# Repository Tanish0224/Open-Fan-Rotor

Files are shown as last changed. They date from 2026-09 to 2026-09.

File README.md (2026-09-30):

# Open-Fan Rotor

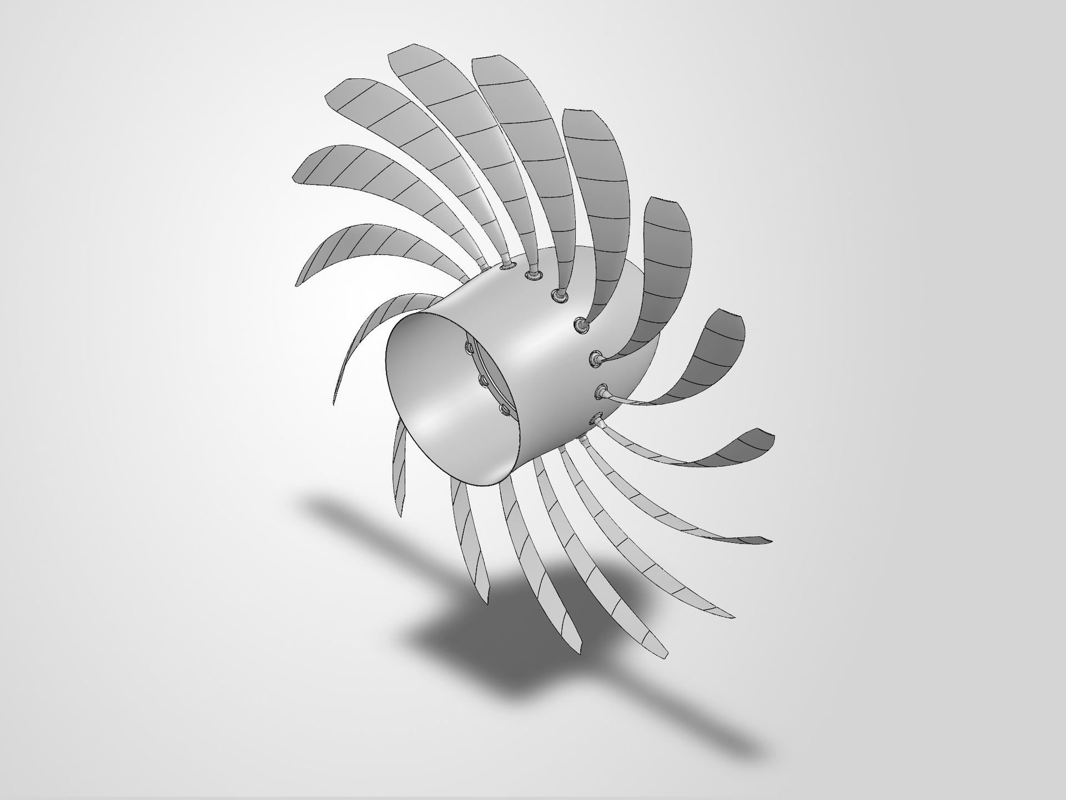
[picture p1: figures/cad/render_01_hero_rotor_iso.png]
16-blade rotor assembly


A 16-blade swept open-fan (unducted) rotor designed for Mach 0.75 cruise at 35,000 ft. The project runs from a
blade-element design through scripted SolidWorks CAD to a 360° CFD campaign in ANSYS Fluent. The first CFD run
exposed a camber error in the built blade. After it was corrected, a series of design changes tested how close
the rotor could get to its 0.75 propulsive-efficiency target. The highest design-RPM efficiency reached was
η_p = 0.572 (case V08).

## Design

| | |
|---|---|
| Design point | Mach 0.75, 10,668 m (35,000 ft) ISA, isolated rotor |
| Diameter / speed | 3.5 m; 1294.5 rpm (rotational tip Mach 0.80, helical tip Mach 1.0966) |
| Design thrust | 14,451.5 N, from a thrust loading τ = 0.08 |
| Method | actuator-disk sizing + Adkins–Liebeck minimum-induced-loss blade design |
| Blades | 16, chosen from a blade-count trade |
| Sweep | circumferential, 44.66° at the tip |

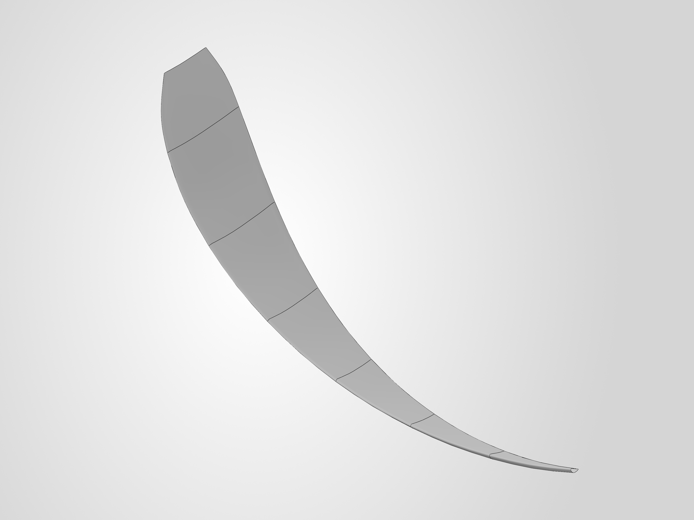
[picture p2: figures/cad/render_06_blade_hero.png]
PRIME blade

*PRIME, the design master blade: circumferential sweep along the span and twist from the root (lower right) to
the tip.*

The blade is generated from the design table by Python scripts driving the SolidWorks API. These are the designs
that matter in the CFD campaign:

| Design | What it is |
|---|---|
| **PRIME** | the v03 design master; its 0.006c trailing edge was too thin to mesh, so the CFD used the variants below |
| **V04cf** | PRIME's design with the camber sign corrected; trailing edge thickened to 0.020c for meshing |
| **V05n16** | NACA 16-series sections in place of NACA 4-digit |
| **V06e** | v06 BEM redesign: design C_l 0.70/0.40 → 0.45/0.26 (root/tip), more chord, root t/c 0.20 → 0.12 |
| **V08** | V06e with the trailing-edge parameter reduced to 0.012c (meshed as 0.0188c) |

BEM design distributions

## Key results

V08 is the reference case and has the highest recorded design-RPM efficiency in this CFD campaign, at
1294.5 rpm and Mach 0.75.

| Thrust | Torque | Shaft power | η_p |
|---:|---:|---:|---:|
| 6548.01 N | 18788.06 N·m | 2.5469 MW | 0.57179 |

- V08 produced about 45 % of the 14,451.5 N design-thrust value; the 0.75 efficiency target was not reached.
- Thrust and torque vary by 1.93 % / 1.12 % over the full second-order history, against a 1 % convergence
  criterion; over the last five checkpoints the variation is 0.80 % / 0.47 %.
- Each case uses a single mesh without prism layers. Mesh independence and experimental validation were not
  assessed.

Results for every case are in [`RESULTS.md`](RESULTS.md).

## What changed

The first run, V03, gave net drag (T = −845.8 N) while absorbing shaft power. Measuring the built blade showed
that the section camber was on the wrong side of the chord for the direction of rotation. Flipping it (V04cf)
gave positive thrust: 4209.9 N at the last checkpoint, although that run never settled. PRIME itself still
carries the error; it is retained unchanged as the record of the built design.

From the corrected blade, the section family was changed first (V05n16), then the BEM loading and chord
distribution (V06e), and finally the trailing-edge parameter (V08). V06e changes several parameters at
once, so these are staged design iterations rather than one-parameter experiments.

Three changes were then tested around V08: a uniform de-pitch (V10), 6° more sweep (V12) and a local root
de-pitch (V15). All three lowered efficiency and missed the predictions written before each run. A hub boundary-condition test (V14)
showed that the negative loading near the root does not come from the hub boundary layer in this model. The
loading plots show the pattern: the outer span gets close to the design loading, while the inner half stays well
below it.

Radial loading

The structural side of the rotor, with root modules, a 16-station carrier and a spinner shell, was built as a
fully mated CAD assembly, and the blade retention was checked with screening FEA in ANSYS MAPDL.

## More detail

| | |
|---|---|
| [`design/`](design/) | design point, BEM method, blade-count trade, the two design families |
| [`cad/`](cad/) | how PRIME was built, the CFD geometries, CAD vs meshed trailing edge, naming |
| [`cfd_method/`](cfd_method/) | solver setup, mesh, boundary conditions, convergence criteria |
| [`cfd_campaign/`](cfd_campaign/) | the campaign case by case, including what did not work |
| [`RESULTS.md`](RESULTS.md) | every recorded CFD result, including diagnostic and off-design cases |
| [`LIMITATIONS.md`](LIMITATIONS.md) | numerical and modelling limitations |
| [`structural/`](structural/) | structural assembly and screening FEA |
| [`reproducibility/`](reproducibility/REPRODUCE.md) | what can be re-run from this repository |
| [`EVIDENCE_INDEX.md`](EVIDENCE_INDEX.md) | where each number and claim comes from |
| [`figures/`](figures/) | all figures and their source data |
| [`reports/`](reports/) | lessons learned |
| [`history/`](history/) | superseded geometry, old drawings and cases without a result |

This repository has not undergone independent external review.

Project and analysis by **Tanish Shetty**. Tools: Python (NumPy, SciPy, Matplotlib), SolidWorks 2026 API,
ANSYS Fluent 2025 R1, ANSYS MAPDL 2025 R1. Code is MIT-licensed. CAD, drawings, figures and data are covered by
[`ASSET_NOTICE.md`](ASSET_NOTICE.md).

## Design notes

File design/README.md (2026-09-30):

# Design (BEM)

An open fan drops the nacelle, which helps propulsive efficiency but leaves the blade tips in supersonic relative
flow even at moderate flight Mach numbers. Without a duct, sweep is the main way to manage that. The rotor was
designed around this constraint. The blade-element (BEM) model here sets the geometry, and the CFD campaign
measures how the built rotor actually performs.

## Design point

| Quantity | Value | Basis |
|---|---|---|
| Flight condition | Mach 0.75, 10,668 m (35,000 ft) ISA | requirement |
| Diameter | 3.5 m | design decision |
| Rotational tip Mach | 0.80 | requirement → 1294.49 rpm, ω = 135.559 rad/s |
| Helical tip Mach | 1.0966 | calculated, √(0.75² + 0.80²) |
| Thrust loading τ = T / (ρ A V0²) | 0.08 | design decision (no aircraft was defined, so there is no aircraft-level thrust requirement) |
| Design thrust | 14,451.5 N | output |

## Method

`openfan_design.py` implements actuator-disk sizing and an Adkins–Liebeck minimum-induced-loss blade-element
design. It uses a Prandtl tip/hub loss factor, closed-form NACA 4-digit sections and a low-order section-drag
estimate. `run_phase1_design.py` runs the design and the blade-count trade.

- **Blade count** is an output. Counts of 14–18 pass the aspect-ratio and chord bounds
  (`results/blade_count_trade.csv`). The smallest count within 0.5 % of the best efficiency among them was chosen:
  **B = 16**.
- **Sweep** follows from a leading-edge-normal Mach limit of 0.78, through cos Λ = 0.78 / M_helical. That gives
  44.66° at the tip. A later check showed that this flat-wing relation over-credits the relief for circumferential
  sweep, so the sections run above their own critical Mach.
- **Internal checks.** Seven closure checks pass, including a 41 → 81 station refinement (`gate_G0` and
  `station_independence` in `results/design_summary.json`). They confirm that the model solves its own equations
  consistently.

## Two design families

| File | Family | Design C_l root / tip, root t/c | Torque | η (model) | Used for |
|---|---|---|---|---|---|
| `results/design_summary.json` | v03 | 0.70 / 0.40, 0.20 | 29,372 N·m | 0.8072 | V03, V04cf, V05n16 |
| `results/design_summary_v06.json` (from `run_v06_design.py`) | v06 | 0.45 / 0.26, 0.12 | 29,818 N·m | 0.7951 | V06e, V08, V10, V12, V14, V15, V16 |
| `results/bem_at_v11_rpm.json` | v06 blade at 1000 rpm, matched thrust | — | 44,073 N·m | 0.6964 | a bound only; not a prediction of V11 |

Both families have the same design thrust (14,451.5 N). Compare each CFD case with its own family; every figure
names the family it uses.

design distributions

## BEM vs CFD

The CFD cases reach only 22–45 % of the design thrust, so BEM and CFD are never compared at matched thrust. The
efficiencies are therefore not directly comparable. The figure below uses BEM as the design reference.

BEM vs CFD

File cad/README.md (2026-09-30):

# CAD and geometry

## How the blade was built

The blade is generated from the BEM design table (`design/results/`) by Python scripts that drive the SolidWorks
API. After each build, a separate script re-opens the part and checks it against the design.

- **v01** failed its own geometry check. The cause was faceted section profiles, which were replaced with smooth
  two-spline sections.
- **v02** passed its check, but a later coordinate check showed the sweep had been built as 0.757 m of axial
  rake, with the tip at 1.879 m instead of 1.75 m. It is kept in `history/superseded_geometry/`.
- **v03 (PRIME)** builds the sweep circumferentially, with 6 mm of rake. It is the design master.

## PRIME

PRIME is `openfan_blade_v03_G1_PRIME_VERIFIED.SLDPRT`, built by `scripts/blade_geometry_v03.py`.

| | |
|---|---|
| SHA-256 | `f5d54c78d1596cdd4fd3df130d34287fe25768e99919c7a82be7b751ab17aeca` |
| Geometry check | 12 of 12 checks passed, before saving and after re-opening (`structural/verification/blade_v03_G1_PRIME_verification.json`) |
| "VERIFIED" in the name | refers to that geometry check: body count, validity, volume, true radius, axial rake, sweep and save/re-open. It says nothing about aerodynamic or structural performance. |
| Known issue | the section camber is on the wrong side of the chord for the direction of rotation. The CFD found it (V03); PRIME uses the same section-placement code. PRIME is retained unchanged as the record of the built design. |

The native SolidWorks file is not included; the hash above identifies it.

| Axial view | Side view |
|---|---|
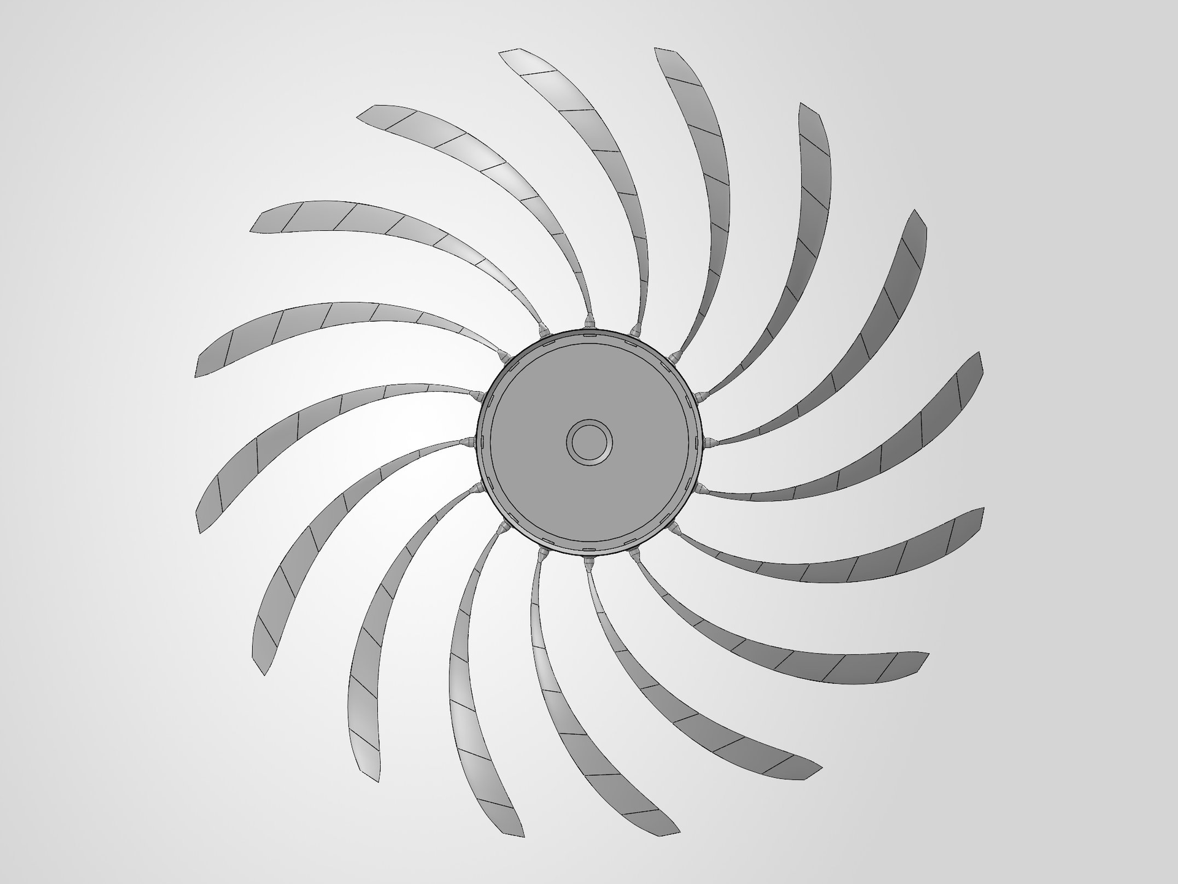
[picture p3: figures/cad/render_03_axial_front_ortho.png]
axial
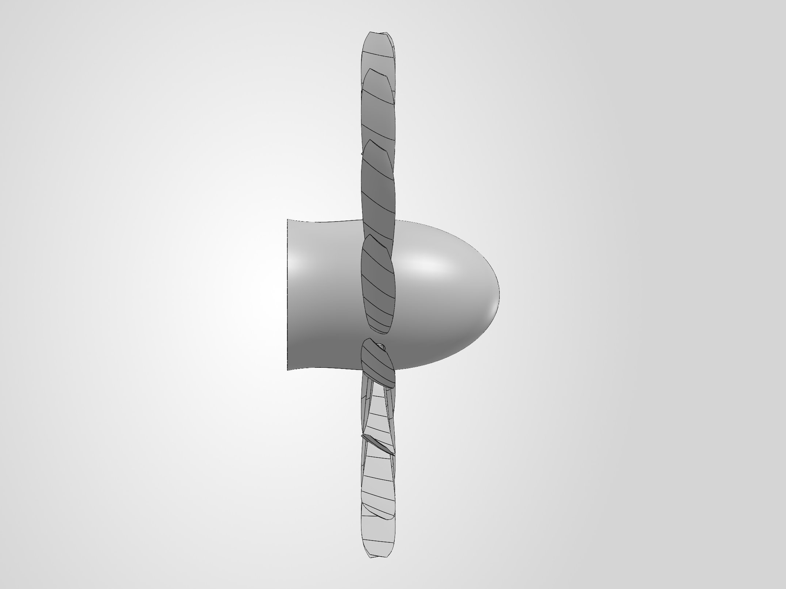
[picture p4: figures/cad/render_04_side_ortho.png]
side
|  |  |

## CFD geometries (`cfd_derivatives/`)

The CFD never used PRIME directly: its 0.006c trailing edge could not be meshed. Each case used its own geometry,
built by the same generator scripts. V03 to V05n16 use PRIME's v03 design table (V05n16 changes the section
family); V06e onward use the v06 design table. The STEP files are the exported geometries.

| File | Case(s) | Change from its parent |
|---|---|---|
| `openfan_blade_v03_CFD_SINGLELOFT.step` | V03 | PRIME with the trailing edge thickened to 0.020c (camber error still present) |
| `openfan_blade_v04_CFD_CAMBERFIX_SINGLELOFT.step` | V04cf | camber sign corrected |
| `openfan_blade_v05_CFD_NACA16_SINGLELOFT.step` | V05n16 | NACA 16-series sections |
| `openfan_blade_v06_CFD_SINGLELOFT.step` | V06, V06c, V06e | v06 BEM design (lower C_l, thinner root) |
| `openfan_blade_v08_CFD_SINGLELOFT.step` | V08, V14 | trailing-edge parameter 0.012c |
| `openfan_blade_v09_CFD_SINGLELOFT.step` | V09, V13 | trailing-edge parameter 0.006c (PRIME's value); could not be meshed |
| `openfan_blade_v10_CFD_SINGLELOFT.step` | V10 | uniform de-pitch −1.77° |
| `openfan_blade_v11_CFD_SINGLELOFT.step` | V11 (1000 rpm, off-design) | re-twisted for 1000 rpm |
| `openfan_blade_v12_CFD_SINGLELOFT.step` | V12 | sweep +6° |
| `openfan_blade_v15_CFD_SINGLELOFT.step` | V15 | root de-pitch −2.40° → 0 at r/R 0.55 |
| `openfan_blade_v16_CFD_SINGLELOFT.step` | V16 (not solved) | root re-pitch +2.40° → 0 at r/R 0.55 |

## Trailing edge: CAD value vs meshed value

The mesher did not resolve the trailing-edge thickness set in CAD. The meshed thickness was measured from the
blade-surface mesh (outboard mean, r/R ≥ 0.70). The measurements are in `cfd_campaign/<case>/te_thickness_*.json`.

| CAD parameter | Cases | Meshed thickness | Mesh | Solution |
|---|---|---|---|---|
| 0.020c | V03, V04cf, V05n16, V06e | 0.0200c (measured for V06e only) | generated | results |
| 0.016c | V08b | — | import failed | none |
| 0.012c | V08, V10, V11, V12, V14, V15, V16 | V08 0.0188c · V11 0.0182c · V12 0.0212c · V15 0.0161c · not measured for V10 (its own mesh, 6,603,468 cells against V08's 6,575,649), V14 (the V08 mesh itself) and V16 (meshed, not solved) | generated | results (V16 not solved) |
| 0.008c | V09b | not measured | generated | solve diverged |
| 0.006c (PRIME) | V09, V13 | — | failed at 7.24 mm and at 2.5 mm size floors | none |

When a result is labelled with a CAD trailing-edge value, read it together with the meshed value.

## Naming

"v03" means three different things in this repository:
- the **v03 blade** (PRIME);
- the **v03 BEM design family**, used by V03 to V05n16 (V06e onward use the v06 family);
- **V03**, the first CFD case.

In prose, CFD cases are written V03 to V16. File and folder names use lower-case tags (`v08`). So a lower-case
tag inside `cfd_campaign/`, or in a `performance_result_*` or `*_orthoquality` file name, is a CFD case.
Elsewhere, "v02", "v03" or "v06" on its own means a CAD or design-table version, as in
`openfan_blade_v03_G1_PRIME_VERIFIED` or `design_summary_v06.json`.

## Scripts (`scripts/`)

`blade_geometry.py` and `blade_geometry_v03.py` generate the section coordinates that the CAD build uses. The
SolidWorks build and check scripts for the structural assembly are in `structural/scripts/`. They need
SolidWorks 2026 to run.

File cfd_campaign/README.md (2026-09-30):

# CFD campaign

The campaign covers 18 labelled case variants (V03–V16) plus one unlabelled +7 % RPM trial. Ten produced a
result: six design-RPM cases, three diagnostics (V03, V04cf, V14) and one off-design case (V11). The other eight
labelled variants and the RPM trial did not produce a result; they are listed in
[`../RESULTS.md`](../RESULTS.md) §4 and [`../history/no_result_cases/`](../history/no_result_cases/). Setup:
[`../cfd_method/`](../cfd_method/). Numbers: [`../RESULTS.md`](../RESULTS.md).

| Folder | Case | Operating point | Role |
|---|---|---|---|
| [`v03_diagnostic_drag_state/`](v03_diagnostic_drag_state/CASE.md) | V03 | design RPM | diagnostic (net drag) |
| [`v04cf_camber_corrected/`](v04cf_camber_corrected/CASE.md) | V04cf | design RPM | diagnostic (unsettled) |
| [`v05n16_naca16_sections/`](v05n16_naca16_sections/CASE.md) | V05n16 | design RPM | design iteration |
| [`v06e_cl_chord_schedule/`](v06e_cl_chord_schedule/CASE.md) | V06e | design RPM | design iteration |
| [`v08_reference_case/`](v08_reference_case/CASE.md) | V08 | design RPM | reference case |
| [`v10_uniform_depitch/`](v10_uniform_depitch/CASE.md) | V10 | design RPM | experiment on V08 |
| [`v11_1000rpm_offdesign/`](v11_1000rpm_offdesign/CASE.md) | V11 | **1000 rpm, off-design** | separate investigation |
| [`v12_sweep_plus6deg/`](v12_sweep_plus6deg/CASE.md) | V12 | design RPM | experiment on V08 |
| [`v14_hub_bc_diagnostic/`](v14_hub_bc_diagnostic/CASE.md) | V14 | design RPM | boundary-condition diagnostic |
| [`v15_root_depitch/`](v15_root_depitch/CASE.md) | V15 | design RPM | experiment on V08 |

Each folder has a `CASE.md` with the change, the prediction written before the run, the outcome and notes.

## How the campaign went

**Camber error (V03 → V04cf).** The first solution, V03, produced net drag (T = −845.8 N) at design RPM while
still absorbing shaft power. The flow showed almost no axial induction, and the incidence was several degrees
above design. Measuring the built blade surfaces showed that the section camber had been placed on the wrong
side of the chord for the direction of rotation. Correcting that one sign (V04cf) gave positive thrust: 4209.9 N
at the last checkpoint. V04cf diverged at iteration 246, so the value is not settled. PRIME uses the same
section-placement code and carries the same error.

camber correction

**Design iterations (V05n16 → V06e → V08).** From the corrected blade, three things were changed in turn:

- the section family to NACA 16-series, with thickness and mean line together (V05n16);
- the BEM loading and chord distribution: lower design C_l at root and tip, more chord and a thinner root, all
  changed together (V06e);
- the trailing-edge parameter, from 0.020c to 0.012c (V08).

V06e changes several parameters at once, so these are staged design iterations rather than one-parameter
experiments. V08 gave the highest design-RPM efficiency, η_p = 0.572. Its CAD trailing edge is 0.012c, but the
mesh resolved 0.0188c, so V08 really tests a thinner aft section rather than a 0.012c edge. The V08
prediction was only partly met. Efficiency came out 0.0018 above the predicted band (0.545–0.570), but the
prediction also expected shaft torque to fall, since the change was meant to cut base drag, and torque rose
4.45 % relative to V06e.

**Experiments around V08 (V10, V12, V15).** Each of these changes one design feature of V08. Each run missed
the efficiency prediction written beforehand. The meshes also differ from V08's (V10 +0.4 %, V12 +9.1 %,
V15 −0.4 % in cell count), and the meshed trailing edges of V12 and V15 differ as well. So none of the three is
a perfectly clean one-variable comparison.

| Case | Change | η_p | What it showed | What it did not show |
|---|---|---:|---|---|
| V10 | uniform de-pitch −1.77° | 0.43856 | thrust fell 51 % | the proposed shock mechanism: sectional data were not exported |
| V12 | sweep +6° | 0.53417 | efficiency below both predicted bands | a clean sweep effect (mesh +9.1 %, different meshed trailing edge) |
| V15 | root de-pitch −2.40° → 0 at r/R 0.55 | 0.55670 | root loading got worse, and the change also affected loading outboard | what incidence correction the root actually needs |

experiments
*Change in thrust, torque and efficiency relative to V08, against V08's own full-history thrust spread.*

**Hub boundary layer (V14).** V14 re-runs the V08 case with zero-shear hub walls, with the same geometry and
mesh. The negative root loading got deeper (dT/dr at r/R 0.40 from −1369 to −1858 N/m), so the hub boundary
layer is not what causes it in this model. V14 is a diagnostic, not a design.

**Off-design (V11).** A blade re-twisted for 1000 rpm reached η_p = 0.656. It is the only case that passes both
convergence windows. Speed and twist changed together, so it cannot be compared directly with the design-RPM
cases.

## What did not work

- **More sweep (V12)** and **root de-pitch (V15)** both lowered efficiency. The opposite-sign root change (V16)
  was built and meshed, but it was not solved.
- **Uniform de-pitch (V10)** cut thrust by half. The mechanism behind the prediction was never tested.
- **PRIME's 0.006c trailing edge** could not be volume-meshed at either size floor tried (V09 at 7.24 mm, V13 at
  2.5 mm). A 0.008c version meshed, but its solve diverged (V09b).
- **The design sweep law** over-credits the Mach relief for circumferential sweep. The analysed sections run
  above their own critical Mach at the design condition.

## Files in the case folders

- **Recorded** files are copied byte-for-byte from the project records. That includes the result files,
  loading, polars, trailing-edge and mesh-quality records.
- **Derived** files were produced for this repository from recorded data:
  - `residuals_*.csv`, from the solver logs;
  - `blade_yplus_node_statistics_*.json`, from the blade-surface exports;
  - `campaign_summary.json`, from `reproducibility/verify_results.py`.

  The scripts that produced the residual and y⁺ files are not included.

A few recorded fields need care:

- The stored `rpm` field is stale in some files. V11's reads 1294.49, while ω gives 1000 rpm.
- `settled_within_1pct` refers to the rolling window only.
- The polars for V04cf, V05n16 and V06e were computed on a zero-induction basis that was later found to be
  wrong. They were not regenerated.

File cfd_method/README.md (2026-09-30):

# CFD method

This setup applies to every case in `cfd_campaign/` unless a case page says otherwise. The Fluent settings are in
the journal templates in `journals/`, which are the V08 setup and solve journals with absolute file paths removed.
The journals for V05n16, V06e, V09b, V10, V12 and V15 are identical to V08's apart from the case tag and the
solver-assigned zone ID. V11 differs only in ω. V14 re-reads the V08 case and changes only the hub-wall condition
(`setup_v14_hub_bc_template.jou`).

## Setup

| Item | Setting |
|---|---|
| Solver | ANSYS Fluent 2025 R1, 3-D, steady (pressure-velocity coupling scheme not set in the journals; solver default) |
| Domain | 360° annulus containing all 16 blades; far field to r = 7 m, z = −7 … +10.5 m |
| Frame | multiple reference frame: rotating cylindrical zone r ≤ 2.0 m, z = −1 … +1 m; outer zone stationary |
| Rotation | ω = −135.559045147 rad/s about +z in the case journals (V04cf onward), i.e. 1294.49 rpm about −z; V11: −104.719755 rad/s (1000 rpm) |
| Turbulence | k-ω SST |
| Fluid | air, ideal gas, three-coefficient Sutherland viscosity, energy equation on |
| Inlet / far field | pressure far-field, p = 23,842.27 Pa, T = 218.808 K, Mach 0.75 along +z |
| Outlet | pressure outlet, 23,842.27 Pa |
| Walls | blade and hub no-slip (V14: hub zero-shear) |
| Discretisation | 60 first-order iterations, then second order |
| Schedule | 60 first-order + 9 × 60 second-order iterations requested; force and moment reported at every 60-iteration checkpoint (S1–S10). Fluent's default residual stop ended some runs a few iterations early. |
| Mesh | Fluent Meshing watertight workflow, tetrahedral, size 7.24 mm – 0.5 m, growth 1.2, curvature and proximity sizing; **no prism layers**; about 6–7 M cells |

## Mesh quality

The first 4.0 M-cell mesh diverged in three solves. The cause was degenerate surface triangles carried over from
the CAD tessellation (minimum orthogonal quality of zero), so that mesh was rejected. From then on every
mesh was checked before it was solved. The per-case quality records are in
`cfd_campaign/<case>/openfan_*_vol_orthoquality.json`.

## Forces and efficiency

- Thrust T = −F_z and torque Q = M_z come from Fluent's force and moment reports on the blade walls. Hub walls
  are excluded.
- Shaft power is P = Q·|ω|, and propulsive efficiency is η_p = T·V0/P with V0 = 222.40 m/s.
- η_p is only reported when T > 0 and P > 0. In a windmill or drag state the ratio of two negative numbers can
  look like a plausible efficiency.
- Two separately written parsers (`postprocessing/compute_performance.py` and
  `postprocessing/independent_extract.py`) give identical values for the cases where both were run.

## Convergence

Convergence is judged on thrust and torque over two windows:

| Window | Definition |
|---|---|
| Rolling | peak-to-peak / mean of T and Q over the last 5 checkpoints; 1 % limit |
| Full history | peak-to-peak / mean of T and Q over S2–S10 (all second-order checkpoints); 1 % limit |

Before any CFD was run, a stricter target (G2) was set:
- at least three refined meshes, with < 2 % change between the two finest;
- residuals down at least 4 orders;
- T and Q stationary over the final 500+ iterations;
- y⁺ within the range the wall treatment needs.

No design-RPM case met it. There is one mesh per case, residuals drop about 3 orders, the full-history spread is above
1 % in every case, and y⁺ is too high without prism layers. The original plan was to report no
performance numbers unless G2 was met; instead, the results are reported with their convergence numbers beside
each one ([`../RESULTS.md`](../RESULTS.md)).

convergence

## Post-processing scripts (`postprocessing/`)

| Script | Purpose | Input (not published) |
|---|---|---|
| `compute_performance.py` (+ `bem_reference.py`, `case_omega.py`) | T, Q, P, η from the Fluent transcript; per-family BEM reference; per-case ω | Fluent transcript file (`.trn`) |
| `independent_extract.py` | a second, separately written parser of the force reports | Fluent transcript file (`.trn`) |
| `convergence_character.py` | window statistics and trend test | Fluent transcript file (`.trn`) |
| `measure_te_thickness.py` | meshed trailing-edge thickness from the blade-surface export | blade-surface CSV |

These scripts show how the recorded files were produced. Their inputs, the Fluent transcripts and field exports,
are too large to include (see [`../reproducibility/REPRODUCE.md`](../reproducibility/REPRODUCE.md)). From the
recorded JSON files, `reproducibility/verify_results.py` recomputes shaft power, efficiency, rpm and both
convergence windows. Thrust, torque, mesh counts and the other values are the recorded inputs.

The scripts that produced the sectional polars, blade-loading integrals, velocity triangles, y⁺ statistics,
residual histories and span accounting are not included. Code comments refer to some of them (for example
`sectional_polar_from_cfd.py` and `analyse_blade_loading.py`). Their outputs are in `cfd_campaign/`, unchanged,
but cannot be regenerated from this repository.

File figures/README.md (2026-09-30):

# Figures

Every plot is regenerated by `src/make_figures.py` from data files in this repository. No number on a figure is
typed by hand; each annotation is computed from the plotted case's own data.

The three blade-to-blade field images also need the field exports (`b2b_r75_<case>.csv`). Those are not included
because of their size; they are identified by hash in `reproducibility/unpublished_evidence_register.json`.

Every CFD figure names its case and operating point.

## CFD (`cfd/`)

| File | Case(s) and operating point | Source data | Caption |
|---|---|---|---|
| `cfd_convergence_design_rpm.svg` | V05n16, V06e, V08, V10, V12, V14, V15 — design RPM | `performance_result_*.json` checkpoints | Thrust and torque at each checkpoint, normalised to the last checkpoint. Both convergence windows are shaded with their pass/fail result. |
| `cfd_v11_1000rpm_offdesign_convergence.svg` | V11 — **1000 rpm, OFF-DESIGN** | V11 checkpoints | As above, for the separate off-design investigation. |
| `cfd_v08_residuals.svg` | V08 — design RPM | `residuals_v08.csv` (derived from the solver log) | Scaled residuals: continuity drops 3.0 orders against the 4 required. |
| `cfd_radial_loading_design_rpm.svg` | V06e, V08, V12, V14, V15 — design RPM | `blade_loading_*.json`; BEM from `design_summary_v06.json` | Sectional thrust and torque loading at nine stations against the v06-family BEM design intent. The outer span approaches design loading; the inner half stays well below it, with negative loading near r/R 0.40. |
| `cfd_radial_loading_lineage_v04cf_v05n16.svg` | V04cf, V05n16 — design RPM | `blade_loading_*.json`; BEM from `design_summary.json` | The same, for the earlier cases, against the v03-family BEM. V04cf is unsettled. |
| `cfd_v11_1000rpm_offdesign_radial_loading.svg` | V11 — **1000 rpm, OFF-DESIGN** | `blade_loading_v11.json` | Sectional thrust loading. No BEM curve: the BEM design exists only for design RPM. |
| `cfd_v08_chordwise_cp.svg` | V08 — design RPM | `blade_loading_v08.json` | Chordwise pressure coefficient at four stations. CAD trailing edge 0.012c; meshed 0.0188c. |
| `cfd_v08_summary.svg` | V08 — design RPM | `performance_result_v08_omega135p559.json`, orthoquality, TE, BEM files | V08's headline values, both convergence windows, the mesh and the trailing edge on one card. |
| `cfd_controlled_experiments_vs_v08.svg` | V10, V12, V15, V14 relative to V08 — design RPM | the case result files | Change in thrust, torque and efficiency relative to V08, against V08's full-history thrust spread. V14 is a hub boundary-condition test; V11 is excluded. The meshes of V10, V12 and V15 differ from V08's by +0.4 %, +9.1 % and −0.4 % in cell count, and the meshed trailing edges of V12 and V15 also differ. |
| `bem_reference_vs_cfd_design_rpm.svg` | design-RPM cases | case results; BEM of the matching family | BEM design intent against recorded CFD thrust and torque. Not at matched thrust; BEM is a reference, not a prediction. |
| `cfd_camber_correction_v03_v04cf.svg` | V03, V04cf — design RPM | the two result files | Net drag becomes positive thrust after the camber sign is corrected. V04cf did not settle. |
| `cfd_mach_b2b_r075_design_rpm.png` | V08, V12, V14, V15 — design RPM | field exports (not included) | Absolute-frame Mach on the blade-to-blade surface at r/R 0.75, on one common colour scale. |
| `cfd_v11_1000rpm_offdesign_mach_b2b_r075.png` | V11 — **1000 rpm, OFF-DESIGN** | field export (not included) | The same quantity and colour scale for the off-design case. |
| `cfd_v08_total_pressure_b2b_r075.png` | V08 — design RPM | field export (not included) | Absolute-frame total pressure at r/R 0.75. |

## Design (`design/`)

| File | Source | Caption |
|---|---|---|
| `bem_spanwise_design_v03_v06_families.svg` | `design_summary.json`, `design_summary_v06.json` | Chord, blade angle, design C_l and thickness ratio for the two BEM design families. This is design intent, not CFD. |

## CAD renders (`cad/`)

`render_01`–`render_05` are captures of the actual CAD assembly: PRIME blades, root modules, carrier and shell.
They were cropped to centre the subject.

| File | View |
|---|---|
| `render_01_hero_rotor_iso.png` | 16-blade rotor, front three-quarter view |
| `render_02_rotor_rear_iso.png` | rear three-quarter view |
| `render_03_axial_front_ortho.png` | axial orthographic view (22.5° blade pitch) |
| `render_04_side_ortho.png` | side orthographic view (blade row in a thin radial disc; 6.1 mm axial rake) |
| `render_05_structure_shell_hidden.png` | structure with the spinner shell hidden: root modules and carrier |
| `render_06_blade_hero.png` | PRIME as a single blade: sweep along the span and twist from root to tip |
| `render_07_blade_root_detail.png` | root region, spinner shell hidden: blade roots, root-module collars and carrier rim |

`render_06` and `render_07` were captured directly from the CAD model (PRIME and the assembly) at 3200 × 2400
and 4000 × 3000. Only the camera and, for `render_07`, the shell's display visibility were changed; the geometry
is exactly as saved. `render_06` is cropped to centre the blade.

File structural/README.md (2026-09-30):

# Structural work

There are two parts: a complete CAD assembly of the rotor, and a set of screening-level FEA runs on the blade
root and retention.

## CAD assembly

The PRIME blade was carried into a 16-blade structural assembly:

- 16 root modules (shank, integral flange, bearing seat);
- a 16-station central carrier;
- a spinner shell with 16 cutouts, which is an aerodynamic fairing, not a load path.

The parts are natively mated in SolidWorks rather than placed by transforms. A re-open check records
(`verification/rotor_assembly_v02_final_verification.json`):

| Check | Value |
|---|---|
| components / mates | 34 / 99, all components fully constrained |
| blade pitch | 22.5° at every station |
| blade-to-root interface gap | 0.000000 m |
| minimum blade-to-blade surface distance | 0.2055 m (true surface distance) |
| root-to-tip axial rake | 0.00612 m |
| shell-to-carrier / shell-to-root clearance | 12.11 mm / 9.88 mm at all 16 stations |

Each component has its own check file in `verification/`. The PRIME blade check (12 of 12 geometry checks,
before saving and after re-opening) is in `verification/blade_v03_G1_PRIME_verification.json`.

The sizing of the shank, seat, carrier web and shell was preliminary closed-form work, so the assembly fixes the
geometry but says nothing about structural margins, fatigue, flutter or manufacturability. The native CAD files
are not included. The drawings made from them are in `history/drawings_2026-08/`.

| Rear view | Structure with the shell hidden |
|---|---|
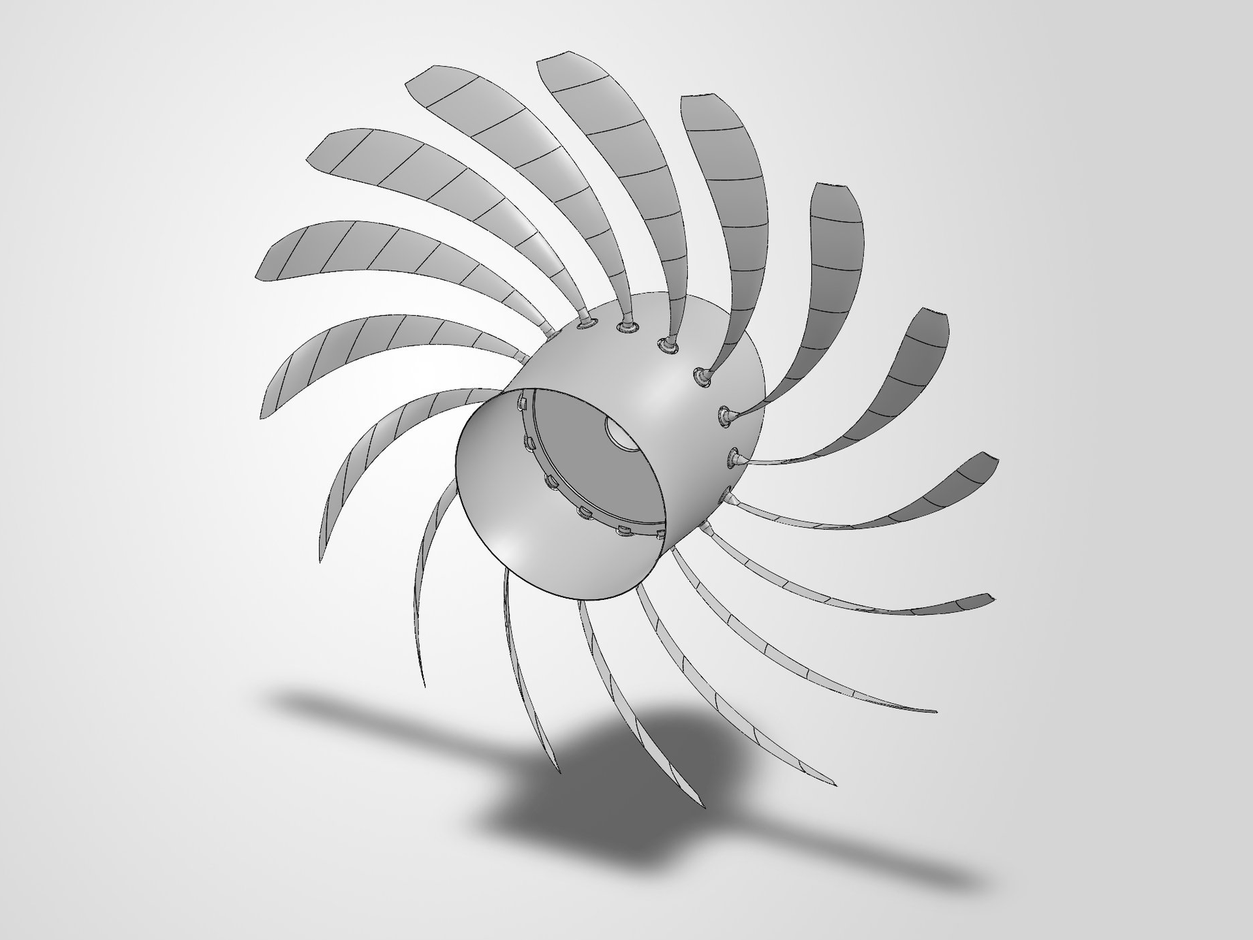
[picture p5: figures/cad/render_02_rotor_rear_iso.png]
rear
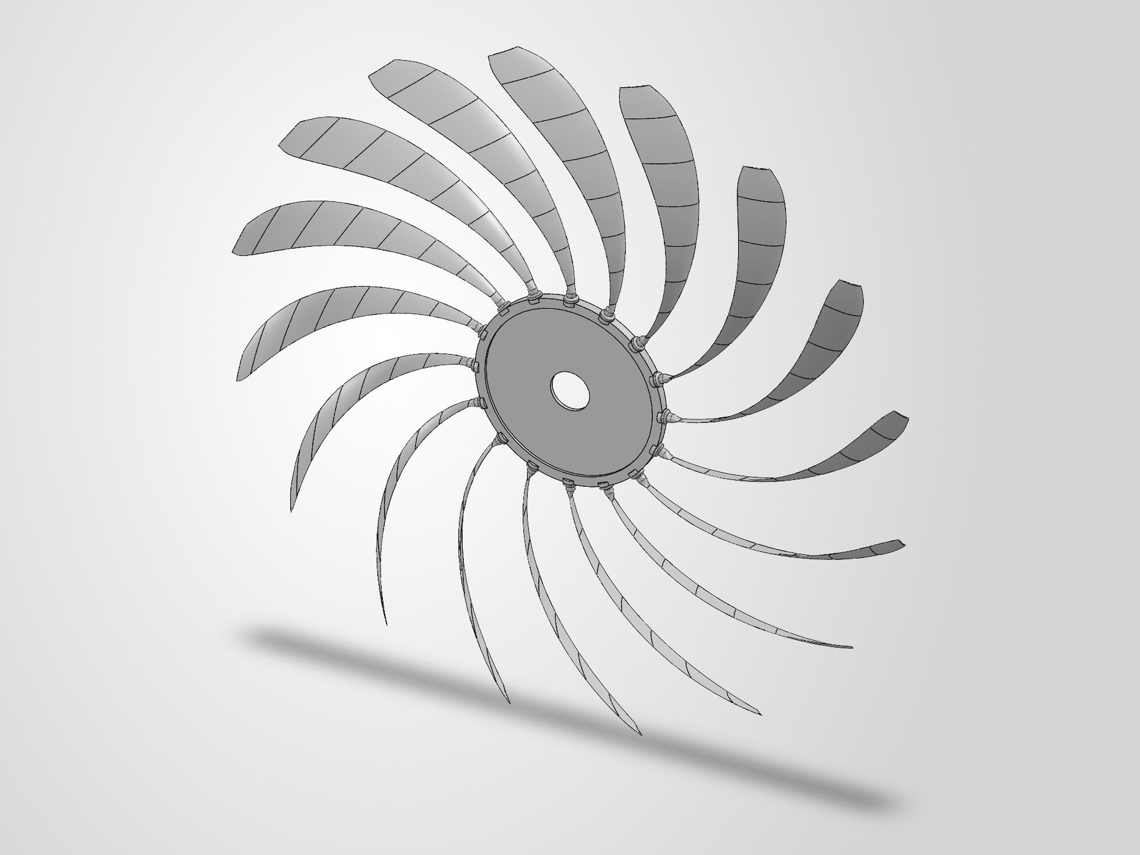
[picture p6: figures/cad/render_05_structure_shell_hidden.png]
structure
|  |  |

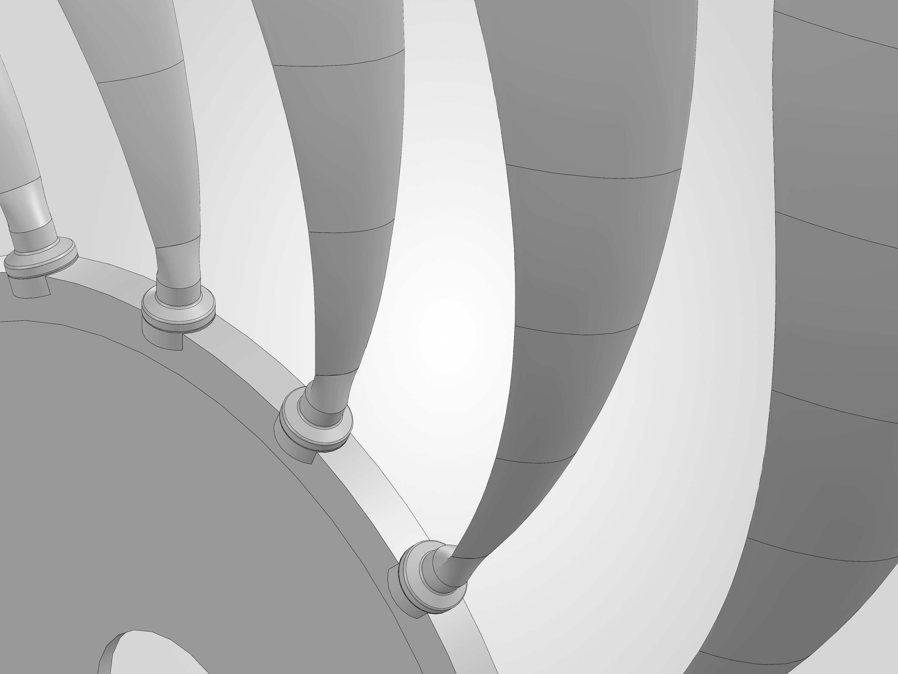
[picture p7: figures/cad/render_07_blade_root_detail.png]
Blade root region

*Root region with the spinner shell hidden: PRIME blade roots in the root-module collars on the carrier rim. This
is the original pad-and-spigot root of the CAD assembly. The later retention study replaced it with a
dovetail-type concept, which the screening FEA found not viable as drawn (Stage 15 below).*

## Screening FEA (ANSYS MAPDL 2025 R1)

After the CAD assembly, a sequence of screening analyses covered the blade root and retention. The stage
reports are identified by hash in `reproducibility/unpublished_evidence_register.json`.

| Stage | What it was | Solved? | Key result | Stage conclusion |
|---|---|---|---|---|
| 1 — root seat | local model of the root seat (solid of revolution) | yes, 10 runs | fillet peak ≈ 770 MPa, K_t 2.74 | screening only; it was not established that the design fails |
| 2 — 22.5° sector | carrier sector plus root module, sector boundary conditions | yes, converged series | fillet peak 815.27 MPa (last refinement step −0.43 %, within a 1 % criterion set beforehand) | peak exceeds a **provisional** 300 MPa allowable (ratio 0.368) |
| 3–14 | load definition, allowables, retention architecture options, CAD | no | decision records | — |
| 15 — Model A | the selected dovetail-type ("C7") retention, 22.5° sector with contact | yes, 14 converged load steps | flank fillet 2526–2537 MPa | **"the C7 geometry at the screening dimensions is not viable as drawn"** |
| 16–17 | failure diagnosis; revised retention CAD | no | — | redesign definition |
| 18 — Model A-R | revised retention, 20 load cases | yes | bending 347 → 665 MPa | governing stress **not mesh-converged**; a full-rotor model is required |
| 19 — mesh closure | refinement study | yes | intermediate fillet converged (−1.51 %); blade peak not converged (+8.46 %, contact-edge singularity) | partial mesh closure |
| 20 — Model C | full 360° rotor, 1,082,992 nodes | yes | axial force balance closes | **global moment balance does not close**; retention not closed |
| 21–23, 25, 27–28 | checks of the moment-balance problem and formulation options | no | missing moment localised to the bolt constraint pairs | open |
| 24, 26 | benchmarks on test blocks (7 solves on a 576-element block; coupling comparison) | yes | constraint and coupling behaviour | benchmarks only, not design results |

**Inputs.** The centrifugal load (163.3 kN in Stages 1–2, 168.71 kN from Stage 15) came from an earlier sizing
step. Bending moments were derived from the design loading. Material allowables were provisional. The stage 1
report does not name the aerodynamic dataset behind its moments.

**What it shows.** The retention region, as first drawn, is highly stressed. The first retention concept fails
its screening, and the full-rotor model has an unresolved moment-balance problem. The work does not give a factor
of safety against a sourced allowable, a fatigue life, or a working retention design.

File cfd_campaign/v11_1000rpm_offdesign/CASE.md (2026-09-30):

# V11 — 1000 rpm off-design case

| | |
|---|---|
| Classification | off-design case (1000 rpm) |
| Operating point | 1000.0 rpm (ω = -104.72 rad/s), flight Mach 0.75, 10,668 m ISA |
| Change | Rotational speed 1294.5 → 1000 rpm AND the blade re-twisted for the new speed (+4.07° root to +7.35° tip). Two coupled changes; their effects cannot be separated. |
| Mesh | 6,545,217 (min orthogonal quality 0.00070; 375 cells below 0.01); no prism layers |
| Thrust T | 5848.05 N |
| Torque Q | 18939.19 N·m |
| Shaft power P = Q·\|ω\| | 1.9833 MW |
| Propulsive efficiency η = T·V0/P | 0.65578 |
| Rolling window (last 5 checkpoints), T / Q | 0.12 % / 0.07 % — within the 1 % bound |
| Full second-order history (S2–S10), T / Q | 0.76 % / 0.37 % — within the 1 % bound |
| Residuals (continuity) | 1 → 0.000998 = 3.00 orders over 547 iterations (≥ 4 orders required by the G2 criterion) |
| Trailing edge | CAD parameter 0.012c; meshed (outboard mean, r/R ≥ 0.70) 0.0182c |
| Blade y+ (node-based) | median 420.7, 95th percentile 533.5, max 1673.0; 92 % of nodes above 300 |
| Validation | none (no experimental or benchmark data) |

## Prediction

η band 0.58–0.67 (central 0.62), written before the run; main check: effective lift-curve slope should rise.

## Outcome

η fell inside its band, and both convergence windows pass. At 1000 rpm, with a re-twisted blade, the case is not comparable with V08.

## Notes

- The stored `rpm` field in the result file reads 1294.49 (stale); ω = −104.72 rad/s ⇒ 1000.0 rpm.
- The solver log shows Fluent's own residual stop at iteration 547 ('solution is converged' on its default residual criterion). An earlier project report stated that V11 ran the full 600-iteration schedule; the log is the primary record. Fluent's default stop is not the convergence criterion used in this repository.
- Mesh tail quality is worse than V08 (minimum orthogonal quality about 4× lower).

## Files in this folder

Recorded files are published unchanged; derived files are marked.

- `blade_loading_v11.json` (recorded)
- `blade_yplus_node_statistics_v11_1000rpm_offdesign.json` (derived)
- `convergence_character_v11.json` (recorded)
- `openfan_v11_vol_orthoquality.json` (recorded)
- `performance_result_v11_omega104p720.json` (recorded)
- `residuals_v11_1000rpm_offdesign.csv` (derived)
- `sectional_polar_v11.json` (recorded)
- `te_thickness_v11.json` (recorded)
- `velocity_triangle_BUILT_v11.json` (recorded)

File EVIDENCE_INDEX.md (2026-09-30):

# Evidence index

Where each number and claim in this repository comes from.

**Evidence classes.**

| Class | Meaning |
|---|---|
| **PRIMARY** | a recorded file produced by the design code, CAD check, solver or its extraction, published unchanged |
| **DERIVED** | computed for this repository from primary data (the source is stated). The comparison scripts are published; the scripts that extracted the residual histories, y⁺ statistics and sectional and loading files are not (see `reproducibility/REPRODUCE.md`) |
| **DESIGN INTENT** | a BEM/analytical design value, not a measurement |
| **DIAGNOSTIC** | a real result that answers a diagnostic question, not a performance question |
| **HISTORICAL** | superseded, kept for the record |

"Register" means `reproducibility/unpublished_evidence_register.json`: a file that exists, identified by name and
SHA-256, but is not published.

## Design

| Claim | Class | Evidence | Method |
|---|---|---|---|
| Design point: Mach 0.75, 10,668 m, D 3.5 m, tip Mach 0.80, τ 0.08 | DESIGN INTENT | `design/results/design_summary.json` (`inputs`, `operating_point`) | defined requirements |
| Helical tip Mach 1.0966; 1294.49 rpm | DESIGN INTENT | `design_summary.json` → `operating_point` | calculation (re-runs identically) |
| 16 blades chosen from a trade study | DESIGN INTENT | `design/results/blade_count_trade.csv`; `run_phase1_design.py` | aspect-ratio and chord bounds + 0.5 % efficiency tie-break |
| Tip sweep 44.66° | DESIGN INTENT | `design/results/design_table.csv` | cos Λ = 0.78 / M_helical |
| The sweep law over-credits Mach relief; sections run above their critical Mach | DERIVED | register: `sweep_relief_audit.json`, `critical_mach_audit.json` | geometric projection check; 2-D panel method |
| BEM η 0.8072 (v03 family), 0.7951 (v06 family); design thrust 14,451.5 N | DESIGN INTENT | `design_summary.json`, `design_summary_v06.json` | Adkins–Liebeck design; 7 internal closure checks (`gate_G0`, `station_independence`) |

## Geometry

| Claim | Class | Evidence | Method |
|---|---|---|---|
| PRIME passes a 12-check geometry check (before saving and after re-opening) | PRIMARY | `structural/verification/blade_v03_G1_PRIME_verification.json` | independent re-open and measurement |
| PRIME identity | PRIMARY | SHA-256 in `cad/README.md`; register (native file) | hash |
| v02 was built with 0.757 m axial rake and a 1.879 m tip | PRIMARY | same file (`v02_Z_span_m`, `v02_true_radius_max_m`) | coordinate readback |
| Camber on the wrong side of the chord in V03 (and in PRIME's section code) | PRIMARY | register: `camber_orientation_check.json`, `camber_stl_check.json`, `STAGE35_CAMBER_INVERSION_ROOT_CAUSE.md` | mean-line direction measured on the solved blade, the CAD source and the exported CAD surfaces |
| CFD derivative geometry per case | PRIMARY | `cad/cfd_derivatives/*.step` | exported CAD |
| Meshed trailing edge differs from the CAD value (0.0161c–0.0212c for 0.012c CAD) | PRIMARY | `cfd_campaign/*/te_thickness_*.json` | measured from the blade-surface mesh |
| 0.006c trailing edge could not be meshed; 0.008c diverged | PRIMARY | register: `v09_TE006_MESH_FAILURE.json`, `v13_TET_INIT_FAILED_definitive_root_cause.json`, `v09b_TE008_DIVERGED.json` | mesher and solver records |

## CFD

| Claim | Class | Evidence | Method |
|---|---|---|---|
| V08 T = 6548.01 N, Q = 18788.06 N·m, P = 2.5469 MW, η_p = 0.57179 | PRIMARY → DERIVED check | `cfd_campaign/v08_reference_case/performance_result_v08_omega135p559.json` → `reproducibility/verify_results.py` → `figures/cfd/cfd_v08_summary.svg` | force report; P = Q·\|ω\|, η = T·V0/P recomputed exactly |
| Values for every other case in `RESULTS.md` | PRIMARY → DERIVED check | `cfd_campaign/<case>/performance_result_*.json` → `campaign_summary.json` | as above |
| V08 passes the rolling window and fails the full-history window | DERIVED | `verify_results.py` from the stored checkpoints (matches `convergence_character_v08.json`) | peak-to-peak / mean against 1 % |
| No design-RPM case passes full-history convergence; V11 (off-design) passes both | DERIVED | `campaign_summary.json` | as above |
| Residual drop about 3 orders | DERIVED | `cfd_campaign/*/residuals_*.csv` (from the solver logs in the register) | log parse |
| Blade y⁺ node-median about 430–440; > 90 % of nodes above 300 | DERIVED | `cfd_campaign/*/blade_yplus_node_statistics_*.json` (from blade-surface exports in the register) | node statistics |
| Mesh cell counts and quality | PRIMARY | `cfd_campaign/*/openfan_*_vol_orthoquality.json`; `history/no_result_cases/` | mesh quality report |
| V11 runs at 1000 rpm (the stored `rpm` field is stale) | PRIMARY + DERIVED | V11 result file (`omega` = −104.719755); `campaign_summary.json` (`rpm_from_omega`) | rpm = \|ω\|·60 / 2π |
| V03 produced net drag; axial induction ≈ 0 and incidence above design | DIAGNOSTIC | V03 result file; register: `operating_points.json` | force report; ring-averaged velocity triangle |
| V14: zero-shear hub walls deepened the root windmill state | DIAGNOSTIC | `cfd_campaign/v14_hub_bc_diagnostic/blade_loading_v14.json`; register: `HUB_BOUNDARY_LAYER_CONFIRMED.json` (the boundary-layer measurement on V08 that motivated the test) | sectional loading at r/R 0.40 |
| V10: prediction failed; mechanism not tested | PRIMARY | V10 result file; register: `v10_prediction.json`, `v10_PITCH_FALSIFIED.json` (the file name refers to the prediction) | pre-registered band vs recorded η; no V10 sectional export exists |
| V12, V15: predictions failed | PRIMARY | result files; register: `v12_prediction.json`, `v12b_prediction_corrected_basis.json`, `v15_prediction.json`, `v15_gate_report.json` | pre-registered bands and gates |
| V16 built and meshed, not solved | PRIMARY | `cad/cfd_derivatives/openfan_blade_v16_CFD_SINGLELOFT.step`; `history/no_result_cases/openfan_v16_vol_orthoquality.json`; register: `V16_PRESOLVE_SIGN_REVERSAL_AUDIT.json` | no case file and no solution exist |
| First 360° mesh rejected on quality; the sector domain abandoned; the sector domain's volume check was too coarse | HISTORICAL | register: `STAGE29_DOMAIN_LOCK_REPORT.md`, `STAGE30_VOLUME_MESH_BLOCKER.md`, `STAGE31_CFD_DIVERGENCE_DIAGNOSIS.md` | mesh-quality and domain-volume measurement |
| Sectional drag decomposition that motivated V08 | DERIVED (model-based) | register: `STAGE38_DRAG_DECOMPOSITION_AND_V08.md` | base-drag correlation applied to the V06e sectional polar |

## Structural

| Claim | Class | Evidence | Method |
|---|---|---|---|
| 34 components, 99 mates, fully constrained; clearances and rake | PRIMARY | `structural/verification/rotor_assembly_v02_final_verification.json` | CAD re-open and measurement |
| FEA stage outcomes (Stage 15 "not viable as drawn"; Stage 20 moment balance does not close; Stages 18–19 not mesh-converged) | PRIMARY (reports not published) | register: the eight FEA stage reports | ANSYS MAPDL screening analyses |

## Figures

Every figure's source data and generating script are listed in [`figures/README.md`](figures/README.md).

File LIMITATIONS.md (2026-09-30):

# Limitations

## Scope

- The 0.75 propulsive-efficiency target was not reached; the highest design-RPM value is 0.572 (V08).
- The design was not optimised. The campaign is a sequence of design iterations and a few experiments around
  V08.
- The CFD results are not compared with experimental or published benchmark data. None exists for this regime:
  compressible flow in axial flight with a supersonic helical tip Mach.
- The structural FEA is screening-level only.

## CFD numerics

1. **Convergence.** No design-RPM case meets the full-history criterion (1 % peak-to-peak on thrust and torque
   over S2–S10). All of them except V10 pass the rolling last-five-checkpoint window. Only V11, the 1000 rpm
   off-design case, passes both. The rolling window was introduced during the campaign. The original target was thrust
   and torque stationary over the final 500+ iterations, and the full-history window is the closer of the two to
   that. ([`RESULTS.md`](RESULTS.md), `cfd_campaign/campaign_summary.json`)
2. **Mesh independence was not assessed.** Each case ran on one mesh of about 6–7 M cells. A 9.1 M-cell mesh
   exceeded the available memory, so a refinement study on the 360° domain was not feasible on this hardware.
   Cell counts also vary between cases relative to V08: −0.4 % to +9.1 % across V10, V12 and V15, and −1.5 % to
   +1.9 % for V05n16 and V06e. These differences are uncontrolled.
3. **Residuals** drop about 3 orders, against a 4-order target
   (`cfd_campaign/*/residuals_*.csv`).
4. **No prism layers.** The blade y⁺ node median is about 430–440, with more than 90 % of blade nodes above 300
   (`cfd_campaign/*/blade_yplus_node_statistics_*.json`). The wall treatment is outside its intended range, so
   separation onset and skin-friction drag are not resolved.

Together these mean the original convergence target (G2 in [`cfd_method/`](cfd_method/README.md)) was not met.

## Models

5. **BEM is the design model, not a prediction of the CFD.** The CFD never reaches the design thrust. The cases
   reach 22–45 % of it, so BEM and CFD efficiencies are not directly comparable. BEM uses a closed-form NACA
   4-digit drag estimate, while the CFD sections from V05n16 on are NACA 16-series.
6. **The design sweep law over-credits Mach relief.** It uses the flat-wing relation M_n = M·cos Λ. For a
   circumferentially swept blade the relief is smaller, and the analysed sections run above their own critical
   Mach at the design condition. (Design checks listed in the unpublished-evidence register.)
7. **Sectional quantities are inferred.** Section lift and drag come from a blade-element inversion of the CFD
   surface data. The polars for V04cf, V05n16 and V06e use a zero-induction basis that was later found to be
   wrong, and they were not regenerated. Absolute incidence carries about ±1° uncertainty from the blade-angle
   reference.

## Geometry in CFD

8. **The CFD blades are not PRIME.** V03 to V05n16 use PRIME's design table; V06e onward use the v06 table. The
   trailing edge was thickened for meshing, and the meshed thickness differs from the CAD value: a 0.012c CAD
   edge meshed as 0.0161c–0.0212c depending on the case ([`cad/README.md`](cad/README.md)). PRIME's own 0.006c
   edge could not be volume-meshed (V09, V13), and a 0.008c edge meshed but the solve diverged (V09b).
9. **Span.** The CFD blade covers r = 0.565–1.725 m against a design span of 0.490–1.750 m, so thrust and torque
   are each about 3 % low.
10. **PRIME still has the camber error** found in V03, because it uses the same section-placement code. PRIME
    is retained unchanged as the record of the built design.

## Individual cases

11. **V10:** the planned mechanism check (sectional drag should fall) could not be done, because sectional data
    were not exported. The prediction failed, but the mechanism was neither confirmed nor ruled out.
12. **V12:** the mesh has 9.1 % more cells and a different meshed trailing edge (0.0212c vs 0.0188c), so the
    sweep effect is not isolated.
13. **V15:** the incidence change was measured at one station over one small blade-angle change, and the only
    lift-slope estimate is a two-point difference. That argues against a stalled root at r/R 0.40, but it does
    not show what correction the root needs. The opposite-sign case (V16) was not solved.
14. **V11** changes speed and twist together and runs at 1000 rpm, so it is not comparable with the design-RPM
    cases.
15. **V14** is a boundary-condition test on V08, not a design.
16. **V13 and V16 have no CFD result.**

## Structural work

17. **The FEA is screening-level.** Loads were partly carried over from an earlier sizing step, and the
    allowables were provisional. The governing stresses in Stages 18 and 19 were not mesh-converged, and the
    full-rotor model (Stage 20) did not close its global moment balance. Stages 24 and 26 were benchmarks on test
    blocks. There is no fatigue, flutter or bird-strike analysis. ([`structural/README.md`](structural/README.md))
18. **The CAD assembly is a geometry lock,** not a manufacturing design. The drawings are reference drawings,
    not for manufacture.

## Reproducibility

19. **Not everything is in the repository.** The mesh, case and solution files are 0.12–0.20 GB each, too large
    to publish. Solver logs and field exports are summarised as derived files, and some records are identified
    only by hash. See [`reproducibility/REPRODUCE.md`](reproducibility/REPRODUCE.md).

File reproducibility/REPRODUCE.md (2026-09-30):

# Reproducibility

What someone with only this repository can and cannot re-derive.

| Stage | Status | What is here | What is missing |
|---|---|---|---|
| **BEM design** | **reproducible now** | `design/openfan_design.py`, `run_phase1_design.py`, `run_v06_design.py` and their outputs | nothing (NumPy only; Matplotlib for the plots written by `run_phase1_design.py`) |
| **Force → P, η, convergence windows** | **reproducible now** | recorded result files with all checkpoints; `reproducibility/verify_results.py` | nothing |
| **Figures from recorded data** | **reproducible now** (plots) / **partially** (field images) | `figures/src/make_figures.py` | the blade-to-blade field exports (hash-identified) for the three field images |
| **Geometry** | **partially reproducible** | CFD-derivative STEP files; section-generation scripts; design tables; PRIME identified by SHA-256 | the native PRIME and structural CAD files; the SolidWorks build needs SolidWorks 2026 |
| **CFD setup** | **partially reproducible** | journal templates (setup, solve, V14 boundary condition); settings table in `cfd_method/` | the mesh and case files (0.12–0.20 GB each, over the repository size limit) |
| **Mesh** | **partially reproducible** | size controls and quality records; the STEP geometry | the meshing journals and surface exports; the mesher's output is not bit-reproducible across versions |
| **CFD solution** | **not reproducible from this repository alone** | — | the case and data files, and ANSYS Fluent 2025 R1 |
| **Post-processing, published scripts** (force extraction, convergence character, trailing-edge measurement, per-case ω, BEM reference) | **partially reproducible** | the scripts in `cfd_method/postprocessing/` and their recorded outputs | Fluent transcript files (`.trn`) and blade-surface exports; the scripts document how the recorded files were made but cannot be re-run without those inputs |
| **Post-processing, scripts not published** (sectional polars, blade-loading integrals, velocity triangles, y⁺ statistics, residual histories, span accounting) | **not reproducible from this repository** | the recorded or derived outputs only (`sectional_polar_*.json`, `blade_loading_*.json`, `velocity_triangle_*.json`, `blade_yplus_node_statistics_*.json`, `residuals_*.csv`) | the generating scripts (some are named in code comments but are not in the repository), the field exports and the solver logs; the older polars were also produced on a zero-induction basis that was later found defective |
| **FEA** | **not reproducible from this repository** | stage conclusions in `structural/README.md`; reports identified by hash | the MAPDL input decks and results; the aerodynamic load dataset behind Stage 1 is not traced |

## Quick checks

```
python reproducibility/verify_results.py        # read-only: recomputes P, eta and both windows for every case
```

Two further commands **write files**, so run them on a copy of the repository, not on the published tree:

```
python figures/src/make_figures.py              # rewrites figures/cfd and figures/design (field images need --field-data)
python design/run_phase1_design.py              # re-runs the BEM design; writes into design/results/ next to the script
```

`run_phase1_design.py` writes into the `results/` folder beside itself. Run from the repository it **overwrites the
recorded design files** and adds a `figures/` folder; run it from a copy of the `design/` folder to leave the
published files untouched (copy `design/` to a scratch location and run the script there). On a copy, it reproduces
the recorded `design_summary.json` exactly. `make_figures.py` rewrites the published figure files; with the library
versions used here it regenerates them byte-for-byte, and other Matplotlib versions may differ in detail.

Software used for the recorded results: Python 3 with NumPy, SciPy and Matplotlib; SolidWorks 2026; ANSYS Fluent
2025 R1; ANSYS MAPDL 2025 R1. The checks above need only Python with NumPy and Matplotlib.

## Files that exist but are not published

`unpublished_evidence_register.json` lists 62 files by name, SHA-256 and size, with the reason each is not
included. They are:

- pre-registered predictions;
- case assessment records;
- solver logs;
- field exports;
- the V08 mesh, case and solution files;
- the PRIME native CAD file;
- the FEA stage reports;
- CFD and design check records.

Their identity can be checked against this register if they are supplied for review.

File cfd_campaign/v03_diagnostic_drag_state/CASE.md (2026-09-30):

# V03 — first CFD state: net drag at design RPM

| | |
|---|---|
| Classification | diagnostic (net drag at design RPM) |
| Operating point | 1294.5 rpm (ω = 135.559 rad/s), flight Mach 0.75, 10,668 m ISA |
| Change | CFD derivative of PRIME with the trailing edge thickened to 0.020c for meshing. Camber was later found to be on the wrong side of the chord. |
| Mesh | 5,988,657 (value from the mesh record; the mesh-quality file is not published); no prism layers |
| Thrust T | -845.78 N |
| Torque Q | 5367.10 N·m |
| Shaft power P = Q·\|ω\| | 0.7276 MW |
| Propulsive efficiency η = T·V0/P | undefined (net drag) |
| Convergence windows | not evaluable (1 stored checkpoint(s)) |
| Validation | none (no experimental or benchmark data) |

## Prediction

None registered.

## Outcome

The rotor produced net drag (T < 0) while absorbing shaft power. Propulsive efficiency is undefined for this state and is not reported.

## Notes

- Only one checkpoint is stored, so neither convergence window can be evaluated from the published file.
- This state led to the camber-orientation check that found the construction error (see V04cf).

## Files in this folder

Recorded files are published unchanged; derived files are marked.

- `performance_result_omega135p559.json` (recorded)

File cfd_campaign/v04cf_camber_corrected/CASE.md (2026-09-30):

# V04cf — camber sign corrected

| | |
|---|---|
| Classification | diagnostic (camber corrected; diverged at iteration 246) |
| Operating point | 1294.5 rpm (ω = 135.559 rad/s), flight Mach 0.75, 10,668 m ISA |
| Change | Single change from V03: the sign of the camber line (the section camber was on the wrong side of the chord for the direction of rotation). |
| Mesh | 5,943,535 (min orthogonal quality 0.00325; 9 cells below 0.01); no prism layers |
| Thrust T | 4209.88 N |
| Torque Q | 19052.16 N·m |
| Shaft power P = Q·\|ω\| | 2.5827 MW |
| Propulsive efficiency η = T·V0/P | 0.36252 |
| Convergence windows | not evaluable (4 stored checkpoint(s)) |
| Validation | none (no experimental or benchmark data) |

## Prediction

None registered.

## Outcome

Thrust became positive at design RPM. The case did not settle: it diverged at iteration 246 and only four checkpoints exist. Two values are stored (last checkpoint and window mean); both are kept.

## Notes

- Sectional polar in this folder uses the zero-induction basis (an extraction defect found later; not regenerated for this case).

## Files in this folder

Recorded files are published unchanged; derived files are marked.

- `blade_loading_v04cf.json` (recorded)
- `convergence_character_v04cf.json` (recorded)
- `energy_ledger_design_rpm_v04cf.json` (recorded)
- `openfan_v04cf_vol_orthoquality.json` (recorded)
- `performance_result_v04cf_omega135p559.json` (recorded)
- `sectional_polar_v04cf.json` (recorded)
- `velocity_triangle_v04cf.json` (recorded)

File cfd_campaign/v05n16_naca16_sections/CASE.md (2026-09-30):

# V05n16 — NACA 16-series sections

| | |
|---|---|
| Classification | design iteration, design RPM |
| Operating point | 1294.5 rpm (ω = 135.559 rad/s), flight Mach 0.75, 10,668 m ISA |
| Change | Section family changed to NACA 16-series thickness on an a = 1.0 mean line; chord, t/c, design C_l, sweep and trailing edge held. |
| Mesh | 6,700,165 (min orthogonal quality 0.00180; 572 cells below 0.01); no prism layers |
| Thrust T | 4997.55 N |
| Torque Q | 16379.44 N·m |
| Shaft power P = Q·\|ω\| | 2.2204 MW |
| Propulsive efficiency η = T·V0/P | 0.50057 |
| Rolling window (last 5 checkpoints), T / Q | 0.64 % / 0.32 % — within the 1 % bound |
| Full second-order history (S2–S10), T / Q | 1.42 % / 0.73 % — outside the 1 % bound |
| Validation | none (no experimental or benchmark data) |

## Prediction

η band 0.434–0.517 (central 0.4755), written before the solve (file `v05_prediction.json`, see the unpublished-evidence register).

## Outcome

η fell inside the predicted band. The case fails the full-history convergence window.

## Notes

- Sectional polar uses the zero-induction basis (not regenerated).
- Residual history for this case is not extracted (its solver log is not in the extracted set).

## Files in this folder

Recorded files are published unchanged; derived files are marked.

- `blade_loading_v05n16.json` (recorded)
- `convergence_character_v05n16.json` (recorded)
- `energy_ledger_design_rpm_v05n16.json` (recorded)
- `openfan_v05n16_vol_orthoquality.json` (recorded)
- `performance_result_v05n16_omega135p559.json` (recorded)
- `sectional_polar_v05n16.json` (recorded)
- `velocity_triangle_v05n16.json` (recorded)

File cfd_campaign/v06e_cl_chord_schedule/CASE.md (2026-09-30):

# V06e — lower design C_l / thinner root (v06-family BEM redesign)

| | |
|---|---|
| Classification | design iteration, design RPM |
| Operating point | 1294.5 rpm (ω = 135.559 rad/s), flight Mach 0.75, 10,668 m ISA |
| Change | BEM redesign: C_l root 0.70 → 0.45, tip 0.40 → 0.26, root t/c 0.20 → 0.12 (more chord). Same thrust design point. Two earlier meshes of this geometry were rejected (memory, wall time); V06e is the third mesh. |
| Mesh | 6,480,343 (min orthogonal quality 0.00191; 586 cells below 0.01); no prism layers |
| Thrust T | 5809.08 N |
| Torque Q | 17987.46 N·m |
| Shaft power P = Q·\|ω\| | 2.4384 MW |
| Propulsive efficiency η = T·V0/P | 0.52984 |
| Rolling window (last 5 checkpoints), T / Q | 0.87 % / 0.45 % — within the 1 % bound |
| Full second-order history (S2–S10), T / Q | 2.06 % / 1.09 % — outside the 1 % bound |
| Residuals (continuity) | 1 → 0.000999 = 3.00 orders over 592 iterations (≥ 4 orders required by the G2 criterion) |
| Trailing edge | CAD parameter 0.020c; meshed (outboard mean, r/R ≥ 0.70) 0.0200c |
| Validation | none (no experimental or benchmark data) |

## Prediction

No prediction file was registered for this change.

## Outcome

The case fails the full-history convergence window.

## Notes

- Sectional polar uses the zero-induction basis (not regenerated).
- Comparisons use the v06-family BEM design (η_BEM 0.7951), not the v03-family value.

## Files in this folder

Recorded files are published unchanged; derived files are marked.

- `blade_loading_v06e.json` (recorded)
- `convergence_character_v06e.json` (recorded)
- `energy_ledger_design_rpm_v06e.json` (recorded)
- `openfan_v06e_vol_orthoquality.json` (recorded)
- `performance_result_v06e_omega135p559.json` (recorded)
- `residuals_v06e.csv` (derived)
- `sectional_polar_v06e.json` (recorded)
- `te_thickness_v06e.json` (recorded)
- `velocity_triangle_v06e.json` (recorded)

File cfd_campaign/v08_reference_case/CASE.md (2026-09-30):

# V08 — reference case

| | |
|---|---|
| Classification | reference case, design RPM |
| Operating point | 1294.5 rpm (ω = -135.559 rad/s), flight Mach 0.75, 10,668 m ISA |
| Change | Trailing-edge parameter 0.020c → 0.012c on the V06e aerodynamic design; every other design parameter identical. |
| Mesh | 6,575,649 (min orthogonal quality 0.00285; 325 cells below 0.01); no prism layers |
| Thrust T | 6548.01 N |
| Torque Q | 18788.06 N·m |
| Shaft power P = Q·\|ω\| | 2.5469 MW |
| Propulsive efficiency η = T·V0/P | 0.57179 |
| Rolling window (last 5 checkpoints), T / Q | 0.80 % / 0.47 % — within the 1 % bound |
| Full second-order history (S2–S10), T / Q | 1.93 % / 1.12 % — outside the 1 % bound |
| Residuals (continuity) | 1 → 0.000999 = 3.00 orders over 590 iterations (≥ 4 orders required by the G2 criterion) |
| Trailing edge | CAD parameter 0.012c; meshed (outboard mean, r/R ≥ 0.70) 0.0188c |
| Blade y+ (node-based) | median 436.4, 95th percentile 557.1, max 1907.3; 93 % of nodes above 300 |
| Validation | none (no experimental or benchmark data) |

## Prediction

η band 0.545–0.570 (central 0.558), written before the run, with the condition that shaft torque must fall. The recorded η was 0.0018 above the band and torque rose 4.45 %, so the base-drag condition was not met.

## Outcome

Highest design-RPM efficiency in the campaign. It passes the rolling window but not the full-history window (1.93 % / 1.12 % against 1 %). Mesh independence and physical validation were not assessed.

## Notes

- The meshed trailing edge (0.0188c) did not match the 0.012c CAD parameter; the result tests a thinner aft section, not a 0.012c edge.
- Used as the reference geometry for V10, V12, V14 and V15.

## Files in this folder

Recorded files are published unchanged; derived files are marked.

- `blade_loading_v08.json` (recorded)
- `blade_yplus_node_statistics_v08.json` (derived)
- `convergence_character_v08.json` (recorded)
- `energy_ledger_design_rpm_v08.json` (recorded)
- `openfan_v08_vol_orthoquality.json` (recorded)
- `performance_result_v08_omega135p559.json` (recorded)
- `residuals_v08.csv` (derived)
- `sectional_polar_v08.json` (recorded)
- `te_thickness_v08.json` (recorded)
- `velocity_triangle_BUILT_v08.json` (recorded)

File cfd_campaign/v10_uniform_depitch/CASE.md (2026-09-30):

# V10 — uniform de-pitch −1.77°

| | |
|---|---|
| Classification | experiment on V08, design RPM |
| Operating point | 1294.5 rpm (ω = -135.559 rad/s), flight Mach 0.75, 10,668 m ISA |
| Change | Blade angle reduced uniformly by 1.77° from V08; everything else held. |
| Mesh | 6,603,468 (min orthogonal quality 0.00261; 232 cells below 0.01); no prism layers |
| Thrust T | 3224.33 N |
| Torque Q | 12062.04 N·m |
| Shaft power P = Q·\|ω\| | 1.6351 MW |
| Propulsive efficiency η = T·V0/P | 0.43856 |
| Rolling window (last 5 checkpoints), T / Q | 1.63 % / 0.70 % — outside the 1 % bound |
| Full second-order history (S2–S10), T / Q | 5.45 % / 2.36 % — outside the 1 % bound |
| Residuals (continuity) | 1 → 0.000999 = 3.00 orders over 571 iterations (≥ 4 orders required by the G2 criterion) |
| Validation | none (no experimental or benchmark data) |

## Prediction

η band 0.56–0.62 (central 0.59), written before the run. Mechanism check: sectional drag should fall.

## Outcome

Prediction failed: η 0.439, with thrust −50.8 % relative to V08. The mechanism check was not done: sectional loading data were not exported for this case, so the proposed mechanism was neither confirmed nor ruled out.

## Notes

- Both convergence windows fail; 484 temperature-limiter events were recorded (V06e and V08: none).

## Files in this folder

Recorded files are published unchanged; derived files are marked.

- `openfan_v10_vol_orthoquality.json` (recorded)
- `performance_result_v10_omega135p559.json` (recorded)
- `residuals_v10.csv` (derived)

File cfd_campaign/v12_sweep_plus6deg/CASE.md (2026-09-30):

# V12 — sweep +6°

| | |
|---|---|
| Classification | experiment on V08, design RPM |
| Operating point | 1294.5 rpm (ω = -135.559 rad/s), flight Mach 0.75, 10,668 m ISA |
| Change | Sweep angle increased by 6.00° along the span from V08. |
| Mesh | 7,173,817 (min orthogonal quality 0.00069; 193 cells below 0.01); no prism layers |
| Thrust T | 5726.35 N |
| Torque Q | 17587.74 N·m |
| Shaft power P = Q·\|ω\| | 2.3842 MW |
| Propulsive efficiency η = T·V0/P | 0.53417 |
| Rolling window (last 5 checkpoints), T / Q | 0.86 % / 0.46 % — within the 1 % bound |
| Full second-order history (S2–S10), T / Q | 1.95 % / 1.06 % — outside the 1 % bound |
| Residuals (continuity) | 1 → 0.00132 = 2.88 orders over 600 iterations (≥ 4 orders required by the G2 criterion) |
| Trailing edge | CAD parameter 0.012c; meshed (outboard mean, r/R ≥ 0.70) 0.0212c |
| Blade y+ (node-based) | median 430.3, 95th percentile 566.3, max 3084.0; 93 % of nodes above 300 |
| Validation | none (no experimental or benchmark data) |

## Prediction

Two predicted bands, both written before the run: A 0.579–0.652 (before CAD); B 0.575–0.647 (corrected basis, before the solve).

## Outcome

Prediction failed: η 0.534, below both bands. Evidence for the normal-Mach mechanism was mixed (lift slope rose at 2 of 9 stations and fell at 5), and the mesh and trailing-edge differences below confound the comparison.

## Notes

- Mesh +9.1 % cells relative to V08 (size controls identical; the mesher responded to the geometry).
- Meshed trailing edge 0.0212c vs V08's 0.0188c from the same 0.012c trailing-edge parameter (the swept CAD differs). A project report stated 0.0182c; the measurement file published here reads 0.0212c.

## Files in this folder

Recorded files are published unchanged; derived files are marked.

- `blade_loading_v12.json` (recorded)
- `blade_yplus_node_statistics_v12.json` (derived)
- `convergence_character_v12.json` (recorded)
- `openfan_v12_vol_orthoquality.json` (recorded)
- `performance_result_v12_omega135p559.json` (recorded)
- `residuals_v12.csv` (derived)
- `sectional_polar_v12.json` (recorded)
- `te_thickness_v12.json` (recorded)
- `velocity_triangle_BUILT_v12.json` (recorded)

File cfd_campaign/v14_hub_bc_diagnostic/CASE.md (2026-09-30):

# V14 — hub-wall boundary-condition test

| | |
|---|---|
| Classification | hub boundary-condition test, design RPM |
| Operating point | 1294.5 rpm (ω = -135.559 rad/s), flight Mach 0.75, 10,668 m ISA |
| Change | V08 case with one boundary condition changed: hub walls set to zero shear (slip). Geometry, mesh and operating point identical to V08. No new CAD. |
| Mesh | identical to V08 (same case file); no prism layers |
| Thrust T | 6247.89 N |
| Torque Q | 18406.41 N·m |
| Shaft power P = Q·\|ω\| | 2.4952 MW |
| Propulsive efficiency η = T·V0/P | 0.55690 |
| Rolling window (last 5 checkpoints), T / Q | 0.83 % / 0.46 % — within the 1 % bound |
| Full second-order history (S2–S10), T / Q | 2.22 % / 1.19 % — outside the 1 % bound |
| Residuals (continuity) | 1 → 0.000995 = 3.00 orders over 593 iterations (≥ 4 orders required by the G2 criterion) |
| Blade y+ (node-based) | median 434.8, 95th percentile 557.0, max 1914.8; 92 % of nodes above 300 |
| Validation | none (no experimental or benchmark data) |

## Prediction

η band 0.59–0.64; main check: root thrust loading at r/R 0.40 must become less negative. Written after the case was built and before the solve.

## Outcome

The root windmill state deepened (dT/dr at r/R 0.40 from −1369 to −1858 N/m), so the hub boundary layer is not its cause in this model. Its η is a diagnostic value, not a design result.

## Notes

- No convergence-character file existed for this case; windows are computed by reproducibility/verify_results.py from the stored checkpoints.

## Files in this folder

Recorded files are published unchanged; derived files are marked.

- `blade_loading_v14.json` (recorded)
- `blade_yplus_node_statistics_v14.json` (derived)
- `performance_result_v14_omega135p559.json` (recorded)
- `residuals_v14.csv` (derived)
- `sectional_polar_v14.json` (recorded)
- `velocity_triangle_BUILT_v14.json` (recorded)

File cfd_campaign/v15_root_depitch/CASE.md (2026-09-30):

# V15 — local root de-pitch

| | |
|---|---|
| Classification | experiment on V08, design RPM |
| Operating point | 1294.5 rpm (ω = -135.559 rad/s), flight Mach 0.75, 10,668 m ISA |
| Change | Blade angle reduced near the root: −2.40° at the hub tapering to 0 at r/R 0.55; outboard geometry bit-identical to V08. |
| Mesh | 6,551,933 (min orthogonal quality 0.00317; 12 cells below 0.01); no prism layers |
| Thrust T | 6057.41 N |
| Torque Q | 17851.56 N·m |
| Shaft power P = Q·\|ω\| | 2.4199 MW |
| Propulsive efficiency η = T·V0/P | 0.55670 |
| Rolling window (last 5 checkpoints), T / Q | 0.86 % / 0.49 % — within the 1 % bound |
| Full second-order history (S2–S10), T / Q | 2.02 % / 1.14 % — outside the 1 % bound |
| Residuals (continuity) | 1 → 0.000994 = 3.00 orders over 570 iterations (≥ 4 orders required by the G2 criterion) |
| Trailing edge | CAD parameter 0.012c; meshed (outboard mean, r/R ≥ 0.70) 0.0161c |
| Blade y+ (node-based) | median 435.7, 95th percentile 549.9, max 960.0; 94 % of nodes above 300 |
| Validation | none (no experimental or benchmark data) |

## Prediction

η band 0.585–0.635; main check: root thrust loading less negative and root torque toward zero. The basis was a cross-case lift slope measured over a 0.104° incidence interval.

## Outcome

Prediction failed, and so did the main check (root dT/dr −1369 → −2487 N/m). The change also altered loading outboard of r/R 0.55 (−64 % at r/R 0.60), so it was not local. A single two-point estimate at r/R 0.40 gives a positive lift slope; that argues against a stalled root at that station but is not sufficient to quantify the correction the root needs.

## Notes

- Meshed trailing edge 0.0161c vs V08's 0.0188c from identical CAD — a confound.
- 450 temperature-limiter events on one cell were recorded.

## Files in this folder

Recorded files are published unchanged; derived files are marked.

- `blade_loading_v15.json` (recorded)
- `blade_yplus_node_statistics_v15.json` (derived)
- `convergence_character_v15.json` (recorded)
- `openfan_v15_vol_orthoquality.json` (recorded)
- `performance_result_v15_omega135p559.json` (recorded)
- `residuals_v15.csv` (derived)
- `sectional_polar_v15.json` (recorded)
- `te_thickness_v15.json` (recorded)
- `velocity_triangle_BUILT_v15.json` (recorded)

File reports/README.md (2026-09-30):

# Lessons learned

1. **Check the built geometry against the design intent, not only against the build script.** Both geometry
   errors in this project passed their own CAD checks: the sweep built as rake (v02), and the camber on the wrong
   side of the chord (v03). Each was found only by measuring the built geometry against what the design meant.
2. **A mesh can pass volume and connectivity checks and still be unusable.** The first 360° mesh diverged because
   of degenerate surface cells. Mesh quality has to be measured before any force is trusted.
3. **A convergence verdict depends on the window.** All design-RPM cases fail the full second-order history
   window. All of them except V10 pass the five-checkpoint window. Both are reported.
4. **Write the prediction before the run.** The three experiments around V08 each missed the prediction written
   down beforehand, and that is what made them informative. V10 also shows the cost of not exporting the data
   needed to test a mechanism: the prediction failed, but the mechanism was never checked.
5. **The CAD value is not the meshed value.** Across cases that share the same 0.012c trailing-edge parameter, the
   meshed trailing edge differed by up to 0.009c from the CAD value. PRIME's own trailing edge could not be
   meshed at all.

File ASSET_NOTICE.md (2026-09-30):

# Asset notice

The MIT License in [`LICENSE`](LICENSE) applies to the **source code** in this repository: the Python scripts and
the Fluent journal templates.

It does **not** apply to the following, which are © 2026 Tanish Shetty, all rights reserved:

- CAD geometry (`cad/cfd_derivatives/*.step`, `history/superseded_geometry/*.step`);
- the engineering reference drawings (`history/drawings_2026-08/*.pdf`);
- the rendered images and figures in `figures/`;
- the recorded CFD, BEM and verification data files.

You may view and download these assets to evaluate and discuss this project. Please ask before reusing,
modifying or redistributing them.

The drawings are reference drawings of a study design. They are **not for manufacture**. No part of this
repository is certified or validated for use in any real system.

No third-party geometry, data or images are included.

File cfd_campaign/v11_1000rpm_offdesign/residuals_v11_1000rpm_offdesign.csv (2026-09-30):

iteration | continuity | x_velocity | y_velocity | z_velocity | energy | k | omega
1 | 1.0000e+00 | 1.9588e-04 | 1.9629e-04 | 1.2117e-07 | 2.1118e-04 | 1.0015e-01 | 4.6566e-02
2 | 7.0054e-01 | 1.7545e-04 | 1.7629e-04 | 4.0075e-05 | 1.4594e-04 | 6.7952e-02 | 4.1310e-02
3 | 4.8239e-01 | 1.3982e-04 | 1.3965e-04 | 3.4870e-05 | 1.1308e-04 | 4.5228e-02 | 3.7094e-02
4 | 3.7658e-01 | 1.2024e-04 | 1.2028e-04 | 3.3082e-05 | 9.1045e-05 | 3.7111e-02 | 3.3775e-02
5 | 3.1611e-01 | 1.0758e-04 | 1.0771e-04 | 3.1531e-05 | 7.8905e-05 | 3.2517e-02 | 3.0919e-02
6 | 2.7600e-01 | 9.8942e-05 | 9.8819e-05 | 3.0413e-05 | 7.4371e-05 | 2.8833e-02 | 2.8564e-02
7 | 2.4641e-01 | 9.2612e-05 | 9.2295e-05 | 2.9733e-05 | 7.2727e-05 | 2.5470e-02 | 2.6446e-02
8 | 2.2534e-01 | 8.7424e-05 | 8.7223e-05 | 2.9264e-05 | 7.1546e-05 | 2.2480e-02 | 2.4574e-02
9 | 2.1180e-01 | 8.3156e-05 | 8.2958e-05 | 2.9144e-05 | 7.0876e-05 | 2.0005e-02 | 2.2893e-02
10 | 2.0298e-01 | 7.9773e-05 | 7.9626e-05 | 2.9342e-05 | 7.0755e-05 | 1.7946e-02 | 2.1294e-02
11 | 1.9625e-01 | 7.7041e-05 | 7.6958e-05 | 2.9862e-05 | 7.0765e-05 | 1.6215e-02 | 1.9942e-02
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

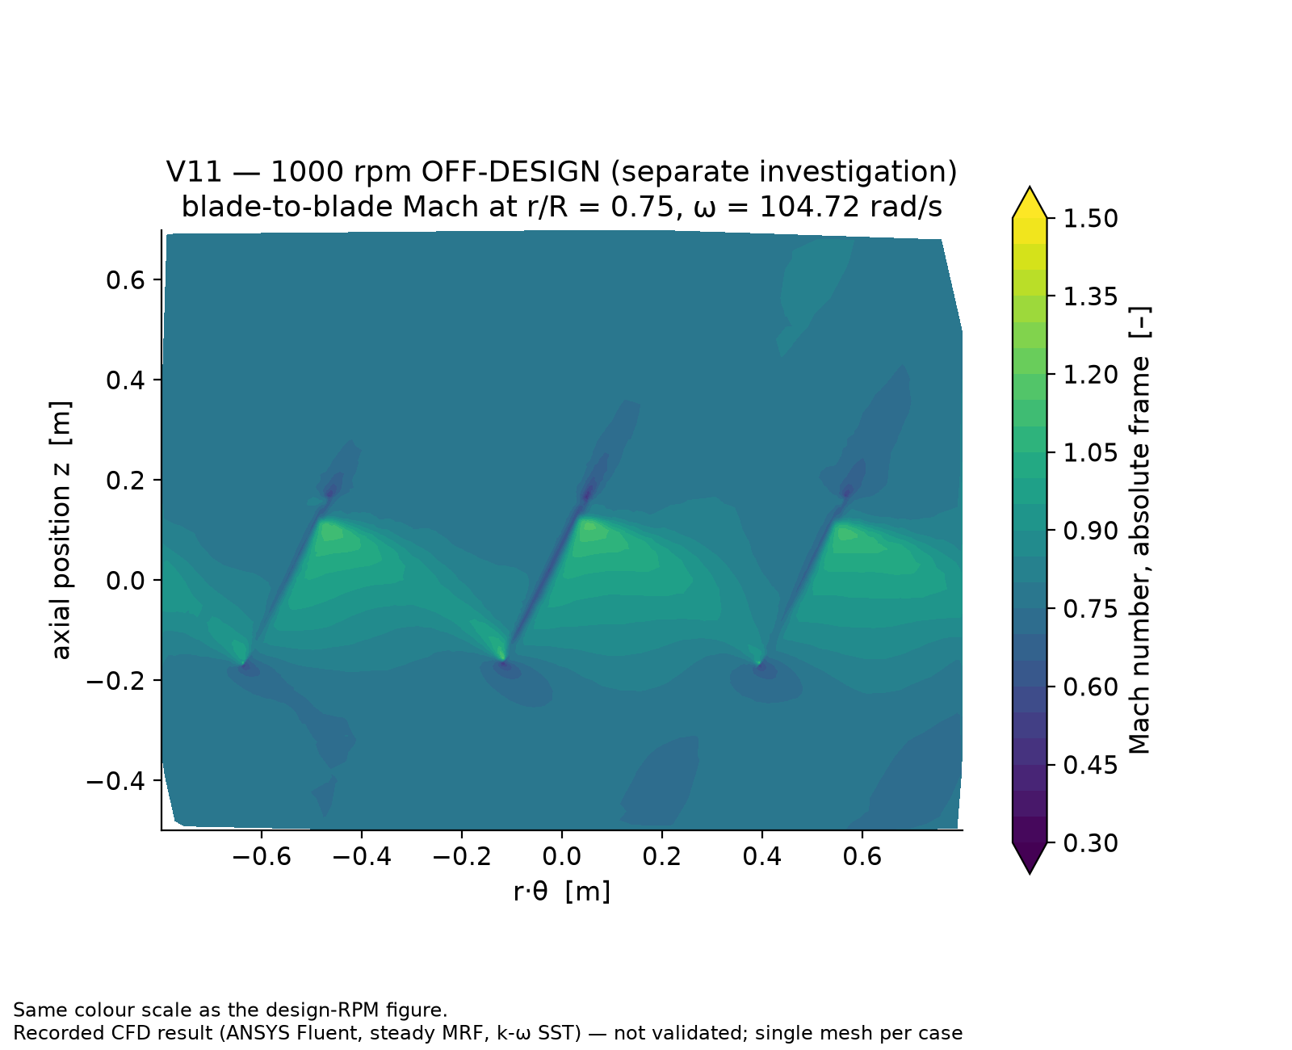
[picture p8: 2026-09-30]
figures/cfd/cfd_v11_1000rpm_offdesign_mach_b2b_r075.png

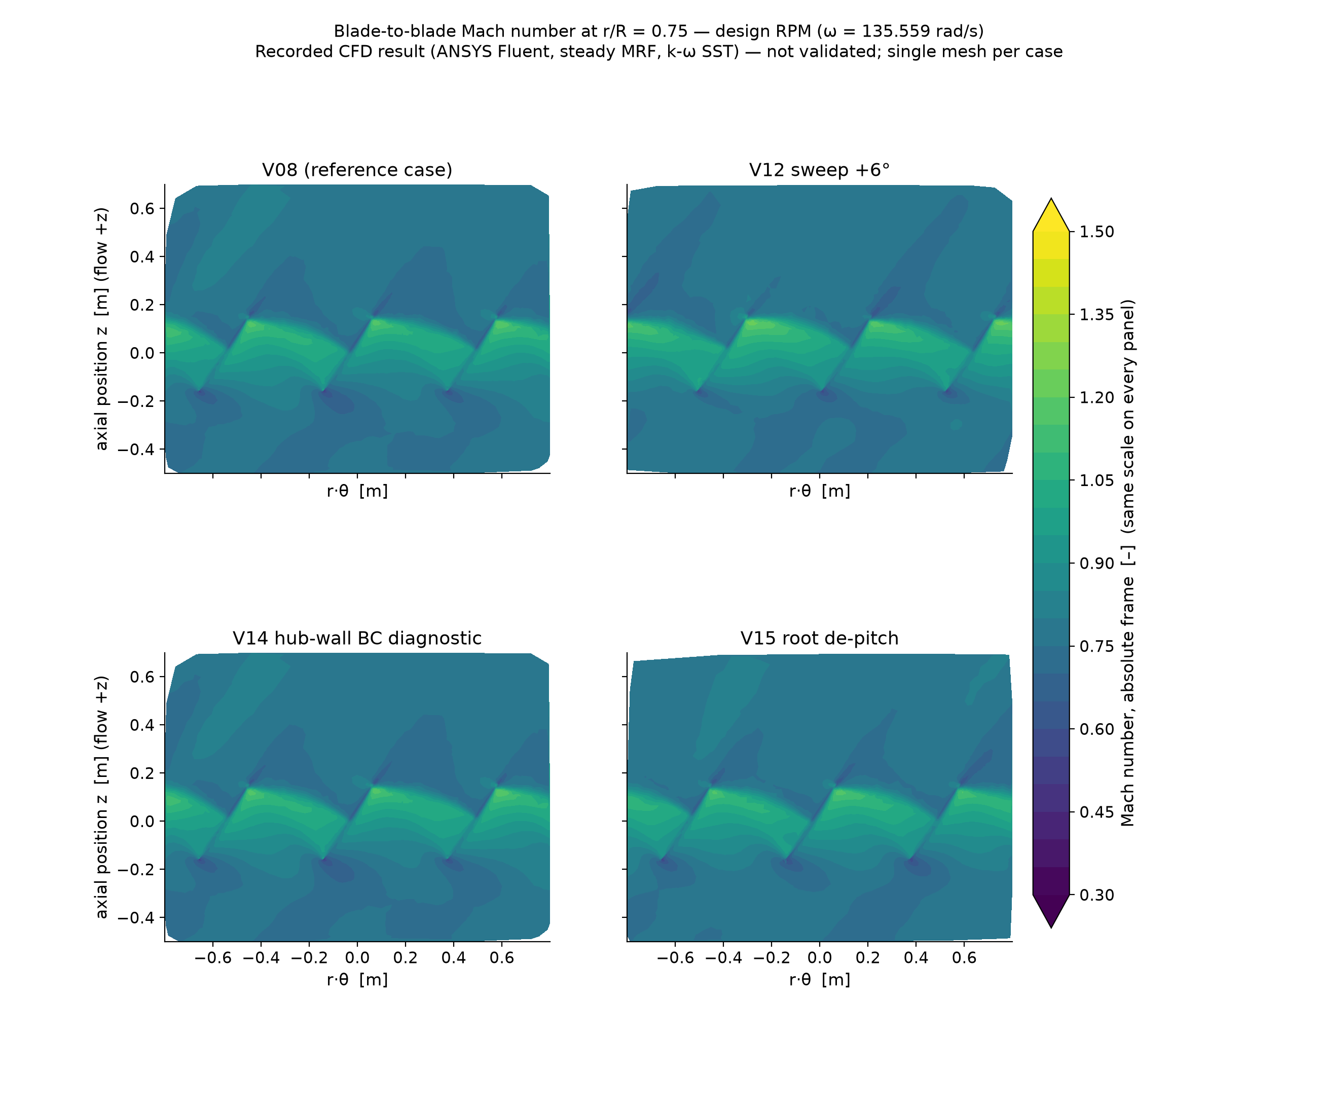
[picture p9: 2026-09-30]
figures/cfd/cfd_mach_b2b_r075_design_rpm.png

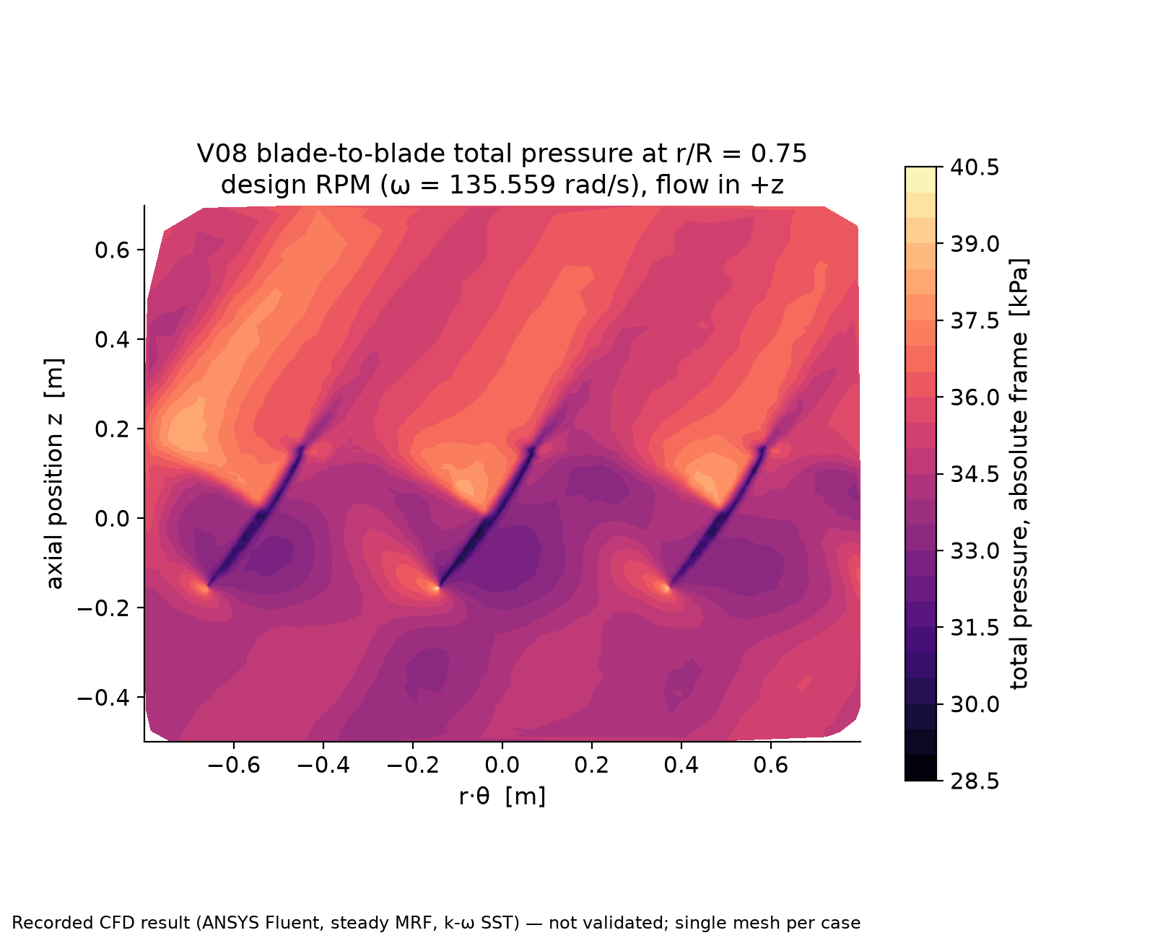
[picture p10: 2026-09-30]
figures/cfd/cfd_v08_total_pressure_b2b_r075.png

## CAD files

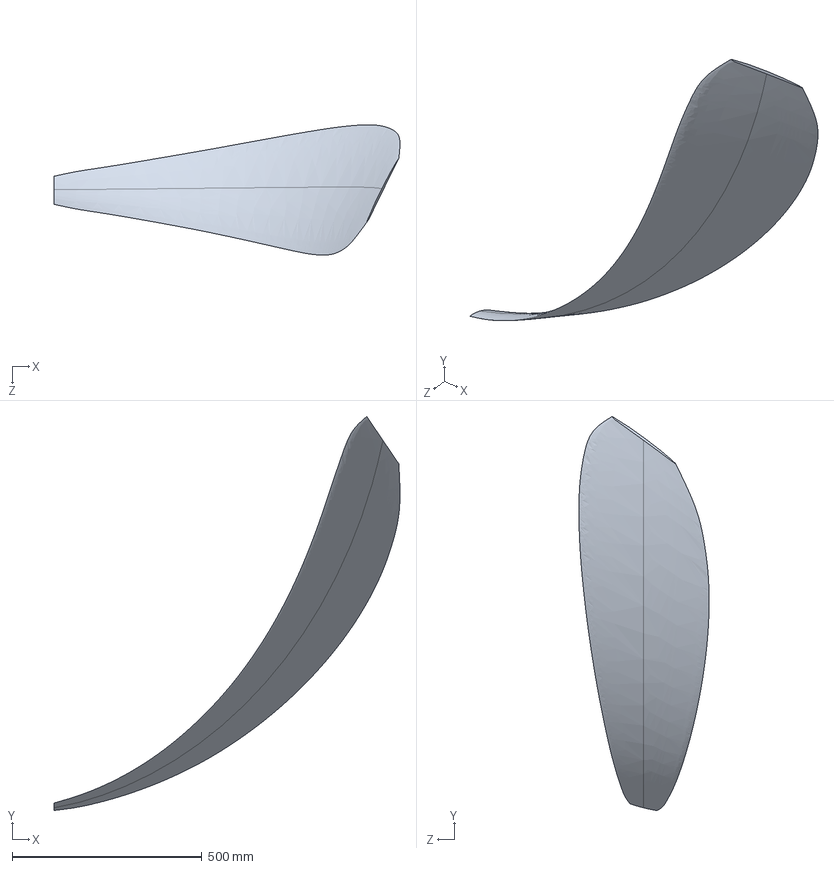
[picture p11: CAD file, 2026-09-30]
cad/cfd_derivatives/openfan_blade_v16_CFD_SINGLELOFT.step
912.2 x 1039.0 x 343.5 mm

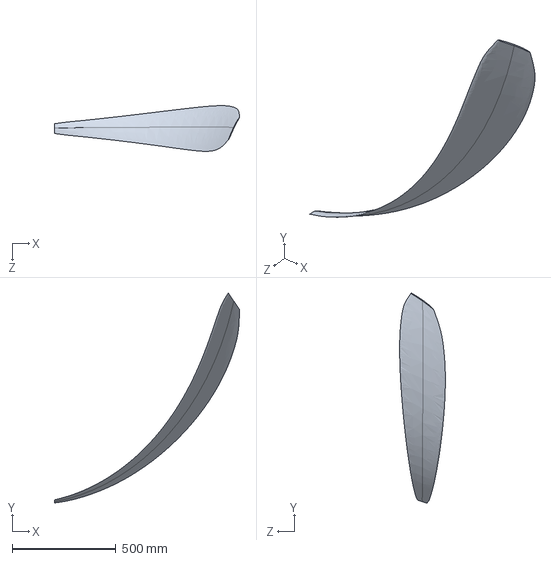
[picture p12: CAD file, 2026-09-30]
cad/cfd_derivatives/openfan_blade_v04_CFD_CAMBERFIX_SINGLELOFT.step
893.8 x 1014.6 x 220.8 mm

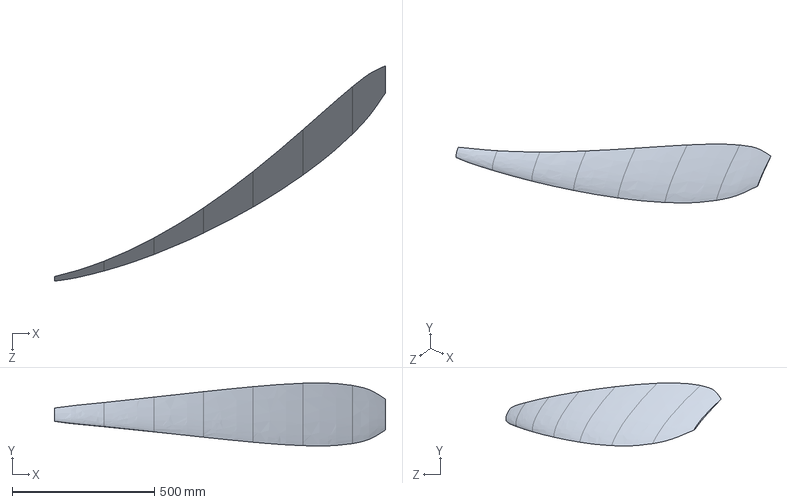
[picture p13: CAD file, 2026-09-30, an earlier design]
history/superseded_geometry/openfan_blade_v02_G1_VERIFIED.step
1163.8 x 221.4 x 757.1 mm

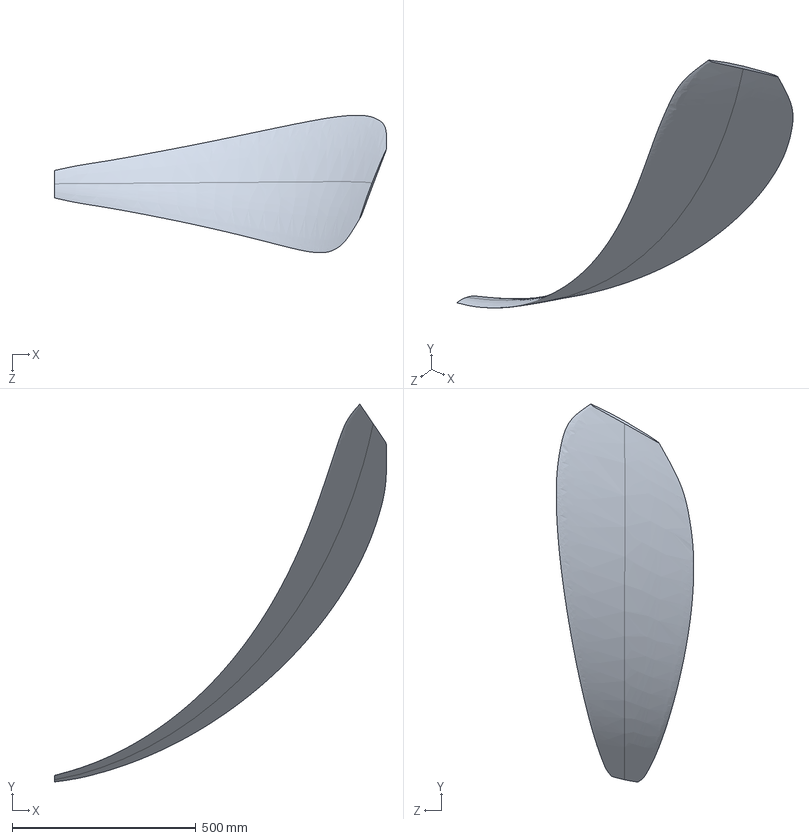
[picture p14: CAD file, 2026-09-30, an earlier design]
cad/cfd_derivatives/openfan_blade_v11_CFD_SINGLELOFT.step
903.6 x 1028.6 x 374.1 mm

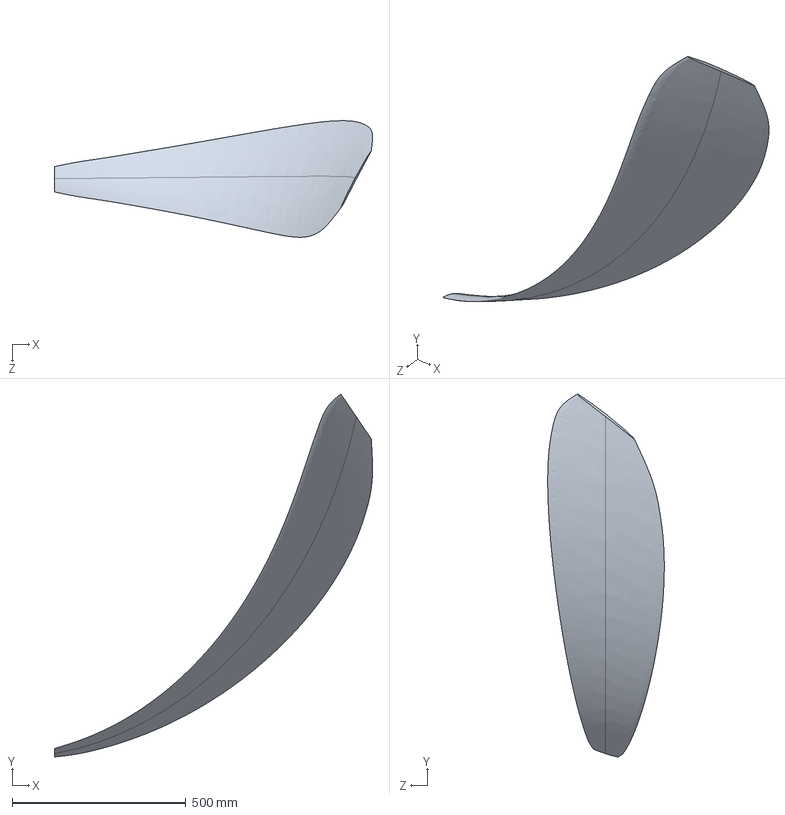
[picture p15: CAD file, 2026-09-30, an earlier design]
cad/cfd_derivatives/openfan_blade_v10_CFD_SINGLELOFT.step
914.2 x 1043.5 x 335.1 mm

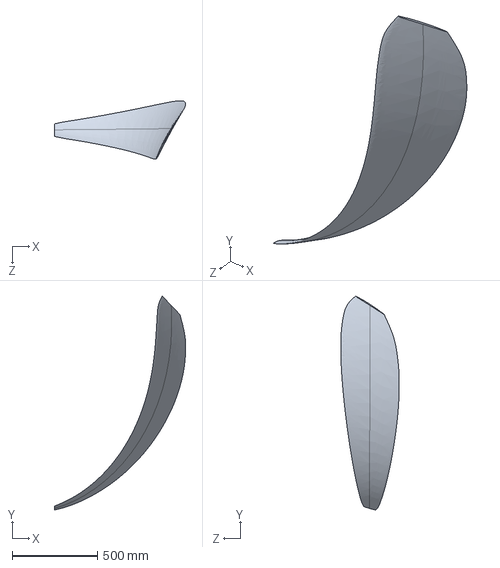
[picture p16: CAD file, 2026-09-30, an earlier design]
cad/cfd_derivatives/openfan_blade_v12_CFD_SINGLELOFT.step
771.6 x 1256.8 x 343.5 mm

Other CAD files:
cad/cfd_derivatives/openfan_blade_v05_CFD_NACA16_SINGLELOFT.step
cad/cfd_derivatives/openfan_blade_v06_CFD_SINGLELOFT.step
cad/cfd_derivatives/openfan_blade_v15_CFD_SINGLELOFT.step
cad/cfd_derivatives/openfan_blade_v03_CFD_SINGLELOFT.step
cad/cfd_derivatives/openfan_blade_v09_CFD_SINGLELOFT.step
cad/cfd_derivatives/openfan_blade_v08_CFD_SINGLELOFT.step

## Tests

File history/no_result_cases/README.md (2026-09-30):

# Cases without a CFD result

These cases produced no performance values.

| Case | What was attempted | Outcome | Record |
|---|---|---|---|
| V06 | V06 geometry, 9,133,396-cell mesh | rejected: exceeded available memory | `openfan_v06_vol_orthoquality.json` |
| V06c | same geometry, 7,609,169-cell mesh | solve aborted: exceeded wall time | `openfan_v06c_vol_orthoquality.json` |
| V07 | intermediate lift/chord schedule | CAD built; import failed (surface-export defect); never solved | — |
| V08b | 0.016c trailing-edge parameter | CAD built; import failed; not re-attempted | — |
| V09 | 0.006c trailing edge (PRIME's value) | tetrahedral initialisation failed at the 7.24 mm size floor | STEP in `cad/cfd_derivatives/` |
| V09b | 0.008c trailing edge | meshed (6,841,077 cells); the solve diverged near iteration 460–470 | `openfan_v09b_vol_orthoquality.json` |
| V13 | V09 geometry at a 2.5 mm size floor | tetrahedral initialisation failed; a mesh attempt, not a design | — |
| V16 | root re-pitch +2.40° → 0 at r/R 0.55 (mirror of V15) | CAD built and volume mesh generated (6,181,870 cells, −5.99 % vs V08); not solved. The pre-solve check did not clear it to run, because its mesh differs from V08's by more than the comparison allows. | `openfan_v16_vol_orthoquality.json`; STEP in `cad/cfd_derivatives/` |

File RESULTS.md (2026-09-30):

# Results

All cases were solved in ANSYS Fluent 2025 R1: steady MRF, k-ω SST, a 360° domain with all 16 blades, one mesh per
case and no prism layers. The values below are read from the result and mesh-quality files in `cfd_campaign/`.
`python reproducibility/verify_results.py` recomputes shaft power, efficiency, rpm and both convergence windows
from those files. Thrust, torque and cell counts are the recorded solver values.

Shaft power is P = Q·|ω| and propulsive efficiency is η_p = T·V0/P, with V0 = 222.40 m/s.

**Convergence windows.** Each window is the peak-to-peak spread of thrust (T) and torque (Q) as a percentage of
their mean, checked against 1 %:

- **rolling:** the last 5 checkpoints (about 300 iterations);
- **full history:** all second-order checkpoints S2–S10 (about 540 iterations). This is the stricter of the two
  and the closer one to the original convergence target.

None of the design-RPM cases meets the full-history criterion. Mesh independence was not assessed, and there is
no experimental data to compare against. See [`LIMITATIONS.md`](LIMITATIONS.md).

---

## 1. Design RPM (1294.5 rpm, |ω| = 135.559 rad/s, Mach 0.75, 10,668 m ISA)

| Case | Role | Geometry change | Thrust [N] | Torque [N·m] | Shaft power [MW] | η_p | Rolling T/Q % | Full-history T/Q % | Mesh (cells) | Notes |
|---|---|---|---:|---:|---:|---:|---|---|---:|---|
| **V05n16** | design iteration | NACA 16-series sections | 4997.55 | 16379.44 | 2.2204 | 0.50057 | 0.64 / 0.32 ✓ | 1.42 / 0.73 ✗ | 6,700,165 | inside its predicted band |
| **V06e** | design iteration | lower design C_l, thinner root (v06 design) | 5809.08 | 17987.46 | 2.4384 | 0.52984 | 0.87 / 0.45 ✓ | 2.06 / 1.09 ✗ | 6,480,343 | — |
| **V08** | **reference case** | trailing-edge parameter 0.020c → 0.012c (meshed 0.0188c) | **6548.01** | **18788.06** | **2.5469** | **0.57179** | 0.80 / 0.47 ✓ | 1.93 / 1.12 ✗ | 6,575,649 | highest design-RPM efficiency in the campaign |
| **V10** | experiment on V08 | uniform de-pitch −1.77° | 3224.33 | 12062.04 | 1.6351 | 0.43856 | 1.63 / 0.70 ✗ | 5.45 / 2.36 ✗ | 6,603,468 | prediction failed; mechanism not tested |
| **V12** | experiment on V08 | sweep +6° | 5726.35 | 17587.74 | 2.3842 | 0.53417 | 0.86 / 0.46 ✓ | 1.95 / 1.06 ✗ | 7,173,817 | prediction failed; mesh +9.1 % and a different meshed trailing edge |
| **V15** | experiment on V08 | root de-pitch −2.40° → 0 at r/R 0.55 | 6057.41 | 17851.56 | 2.4199 | 0.55670 | 0.86 / 0.49 ✓ | 2.02 / 1.14 ✗ | 6,551,933 | prediction and root-loading target both missed |

**V08.** V08 is the reference geometry for V10, V12, V14 and V15. It passes the rolling window, but its
full-history spread of 1.93 % / 1.12 % is above the 1 % criterion. V08, V14 and V15 differ by about 0.015 in η,
which is the same order as V08's own full-history spread. The V08 prediction was only partly met: η came
out 0.0018 above the predicted band, but the prediction also expected a fall in torque, and torque rose 4.45 %
relative to V06e.

For every row, shaft power and efficiency reproduce from the recorded thrust, torque and ω to machine precision.

## 2. Off-design: 1000 rpm

Speed and twist changed together (the blade was re-twisted for 1000 rpm), so V11 is not comparable with the
design-RPM table.

| Case | Operating point | Thrust [N] | Torque [N·m] | Shaft power [MW] | η_p | Rolling T/Q % | Full-history T/Q % | Mesh (cells) | Notes |
|---|---|---:|---:|---:|---:|---|---|---:|---|
| **V11** | 1000.0 rpm (\|ω\| = 104.72 rad/s) | 5848.05 | 18939.19 | 1.9833 | 0.65578 | 0.12 / 0.07 ✓ | 0.76 / 0.37 ✓ | 6,545,217 | inside its predicted band; the only case that passes both windows |

## 3. Diagnostic cases (design RPM)

| Case | Role | What it is | Thrust [N] | Torque [N·m] | η_p | Convergence | Notes |
|---|---|---|---:|---:|---|---|---|
| **V03** | diagnostic | first CFD run: PRIME-based blade with the camber on the wrong side of the chord | −845.78 | 5367.10 | undefined (net drag) | 1 stored checkpoint | led to the camber check |
| **V04cf** | diagnostic | V03 with the camber sign corrected | 4209.88 (last checkpoint) | 19052.16 | 0.36252 (last checkpoint) | diverged at iteration 246 | thrust became positive; not settled |
| **V14** | boundary-condition test | V08 case with zero-shear hub walls; same geometry and mesh | 6247.89 | 18406.41 | 0.55690 | rolling 0.83 / 0.46 ✓; full 2.22 / 1.19 ✗ | root windmilling got deeper, so the hub boundary layer is not its cause in this model; not a design |

## 4. Cases without a result

| Case | Type | What happened |
|---|---|---|
| V06, V06c | mesh attempts | two meshes of the V06e geometry: 9.13 M cells exceeded memory; 7.61 M cells exceeded wall time |
| V07 | no result | CAD built; import failed (surface-export defect); never solved |
| V08b | no result | CAD built (0.016c trailing edge); import failed; not re-attempted |
| V09 | mesh attempt | PRIME's 0.006c trailing edge; tetrahedral initialisation failed at the 7.24 mm size floor |
| V09b | failed solve | 0.008c trailing edge meshed; the solve diverged near iteration 460–470 |
| V13 | mesh attempt | V09 geometry at a 2.5 mm size floor; tetrahedral initialisation failed; no CFD result |
| V16 | not solved | mirror of V15 (+2.40° root re-pitch); CAD built and volume mesh generated (6,181,870 cells, −5.99 % vs V08); not solved |
| +7 % RPM point | no result | thrust oscillated 36 % peak-to-peak and never settled; not used |

## Notes on the recorded data

- **Stale `rpm` field.** The stored `rpm` field reads 1294.49 in every result file, including V11
  (ω = −104.72 rad/s, i.e. 1000 rpm). The operating point is taken from ω and the case definition.
  `campaign_summary.json` lists both.
- **ω sign.** V03–V06e record |ω|; V08 onward record the signed value. From V04cf onward, the journals all set
  ω = −135.559 rad/s about +z, so the rotor's rotation is the same throughout. Shaft power uses |ω|.
- **Iteration counts.** Fluent's default residual stop ended six runs before 600 iterations: V06e at 592, V08 at
  590, V10 at 571, V11 at 547, V14 at 593 and V15 at 570. V12 ran all 600. V05n16's solver log is not in the
  extracted set. This stop is separate from the convergence windows above.
- **Span.** The CFD blade covers r = 0.565–1.725 m against a design span of 0.490–1.750 m, so T and Q are each
  about 3 % low. η_p is affected only at second order.
- **Sectional polars.** The polars for V04cf, V05n16 and V06e were computed on a zero-induction basis that was
  later found to be wrong. Those files were not regenerated. The later cases use the corrected basis.

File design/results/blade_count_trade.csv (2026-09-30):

n_blades | feasible | eta_bem | max_solidity | chord_75R_m | chord_over_D_at_75R | chord_90R_over_R | blade_aspect_ratio | pass_chord_over_D | pass_aspect_ratio | pass_solidity | pass_chord_90R | SELECTABLE
8 | True | 0.7832119410481685 | 0.5059582277090946 | 0.5208930323075683 | 0.14882658065930524 | 0.29513419636388105 | 2.4189227381640537 | True | False | True | True | False
10 | True | 0.7933038829610798 | 0.49684618795874524 | 0.40968486813917315 | 0.11705281946833519 | 0.23920394280378862 | 3.075534631589 | True | False | True | True | False
12 | True | 0.7997305181248059 | 0.49117858408601156 | 0.3368180770928683 | 0.09623373631224809 | 0.2024604874840232 | 3.7408918513972447 | True | False | True | True | False
14 | True | 0.8041005469822564 | 0.48739176222207403 | 0.28526082927841306 | 0.08150309407954659 | 0.1762320523477026 | 4.417010226000032 | True | True | True | True | True
16 | True | 0.807207090017987 | 0.4846179000145224 | 0.24684603554305842 | 0.07052743872658812 | 0.15641911119658441 | 5.104396338503126 | True | True | True | True | True
18 | True | 0.8094865645925187 | 0.4829533712292553 | 0.21714395771894007 | 0.06204113077684002 | 0.14082887515457657 | 5.802602168792 | True | True | True | True | True
20 | True | 0.8111984119321766 | 0.4816388660826143 | 0.19352913472775127 | 0.05529403849364322 | 0.12818006269239673 | 6.510647617851005 | False | True | True | True | False

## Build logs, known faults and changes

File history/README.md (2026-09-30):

# History

Earlier and superseded material, kept for the record. Current results are in [`../RESULTS.md`](../RESULTS.md).

| Path | Status | What it is |
|---|---|---|
| `superseded_geometry/openfan_blade_v02_G1_VERIFIED.step` | superseded | The v02 blade. It passed its own geometry check, but a later coordinate check showed the sweep had been built as 0.757 m of axial rake, with the tip at 1.879 m against a 1.75 m design radius. PRIME (v03) replaced it. "VERIFIED" in the name refers to that earlier check only. |
| `drawings_2026-08/*.pdf` | historical | Reference drawings of the structural assembly, dated 29 August 2026 (not for manufacture). Their notes say no FEA or CFD had been done on the geometry; that was true on that date, and both came later. D02's note calls PRIME the "authoritative aerodynamic master"; that label predates the camber error found through CFD (see [`../cfd_campaign/`](../cfd_campaign/README.md)). The reports cited in the note blocks are not published; the two check files they cite are in [`../structural/verification/`](../structural/verification/). The author field was removed from these copies. |
| `no_result_cases/` | no result | Mesh-quality records for V06 and V06c (meshes rejected on memory and wall time), V09b (meshed; solve diverged) and V16 (meshed; not solved). |

## Earlier project states

- **Before 15 September 2026.** The CFD domain was a 22.5° periodic sector with no volume mesh. Its volume check
  was too coarse to notice that the domain held only about half a blade: the blade spans 36.7° of azimuth, more
  than the 22.5° pitch, and the sector boundaries broke the surface tessellation. It was replaced by the 360°
  annulus used for every result.
- **The first 360° mesh (4.0 M cells)** was rejected on measured quality after three diverged solves.
- **V03**, the first solution, gave net drag. The camber correction superseded it; it is kept as a diagnostic.
- **V04cf** diverged at iteration 246. It is kept in `cfd_campaign/` as a diagnostic.
- **The +7 % RPM point** never settled (thrust oscillated 36 % peak-to-peak) and is not used.
- **Earlier required lift-to-drag estimates** were computed on different angle and loss bases and are not used.

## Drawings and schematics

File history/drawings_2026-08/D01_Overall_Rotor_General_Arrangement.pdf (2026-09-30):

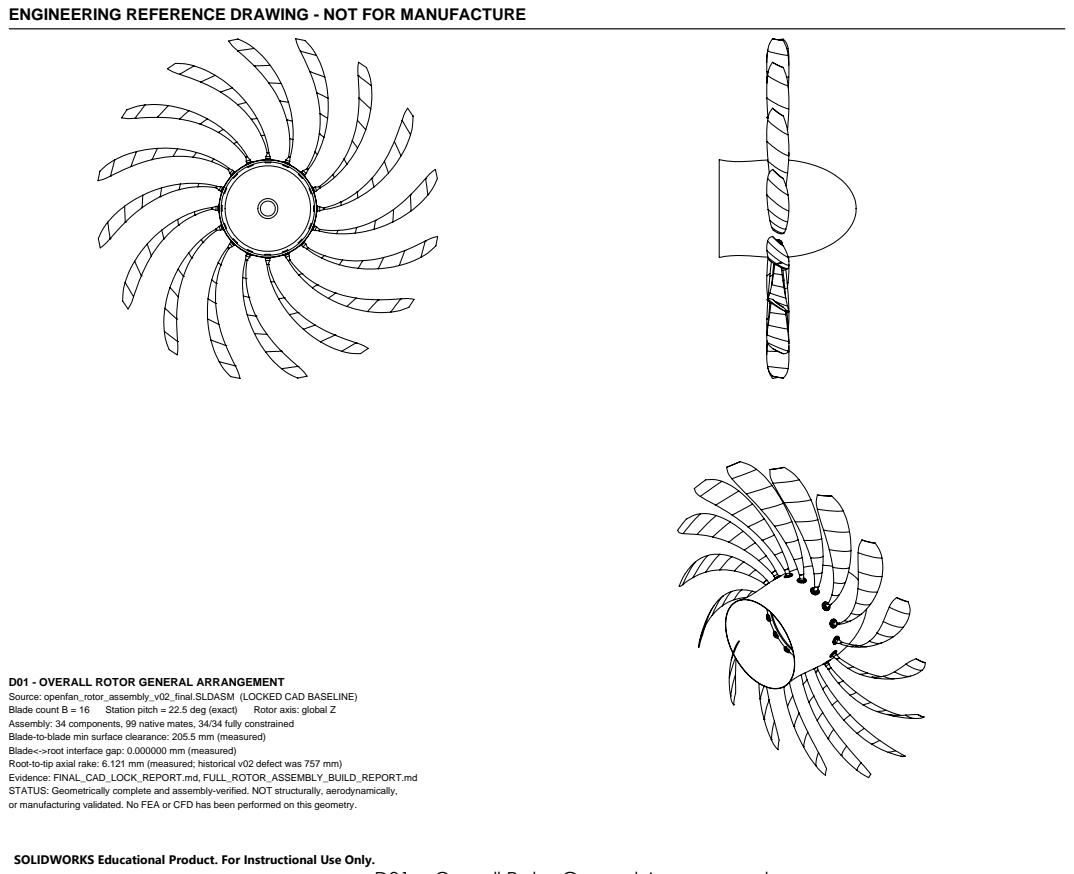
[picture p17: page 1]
Blade count B = 16; Station pitch = 22.5 deg (exact); Rotor axis: global Z

ENGINEERING REFERENCE DRAWING - NOT FOR MANUFACTURE

D01 - OVERALL ROTOR GENERAL ARRANGEMENT
Source: openfan_rotor_assembly_v02_final.SLDASM (LOCKED CAD BASELINE)
Assembly: 34 components, 99 native mates, 34/34 fully constrained
Blade-to-blade min surface clearance: 205.5 mm (measured)
Blade<->root interface gap: 0.000000 mm (measured)
Root-to-tip axial rake: 6.121 mm (measured; historical v02 defect was 757 mm)
Evidence: FINAL_CAD_LOCK_REPORT.md, FULL_ROTOR_ASSEMBLY_BUILD_REPORT.md
STATUS: Geometrically complete and assembly-verified. NOT structurally, aerodynamically,
or manufacturing validated. No FEA or CFD has been performed on this geometry.

SOLIDWORKS Educational Product. For Instructional Use Only.

D01 -- Overall Rotor General Arrangement

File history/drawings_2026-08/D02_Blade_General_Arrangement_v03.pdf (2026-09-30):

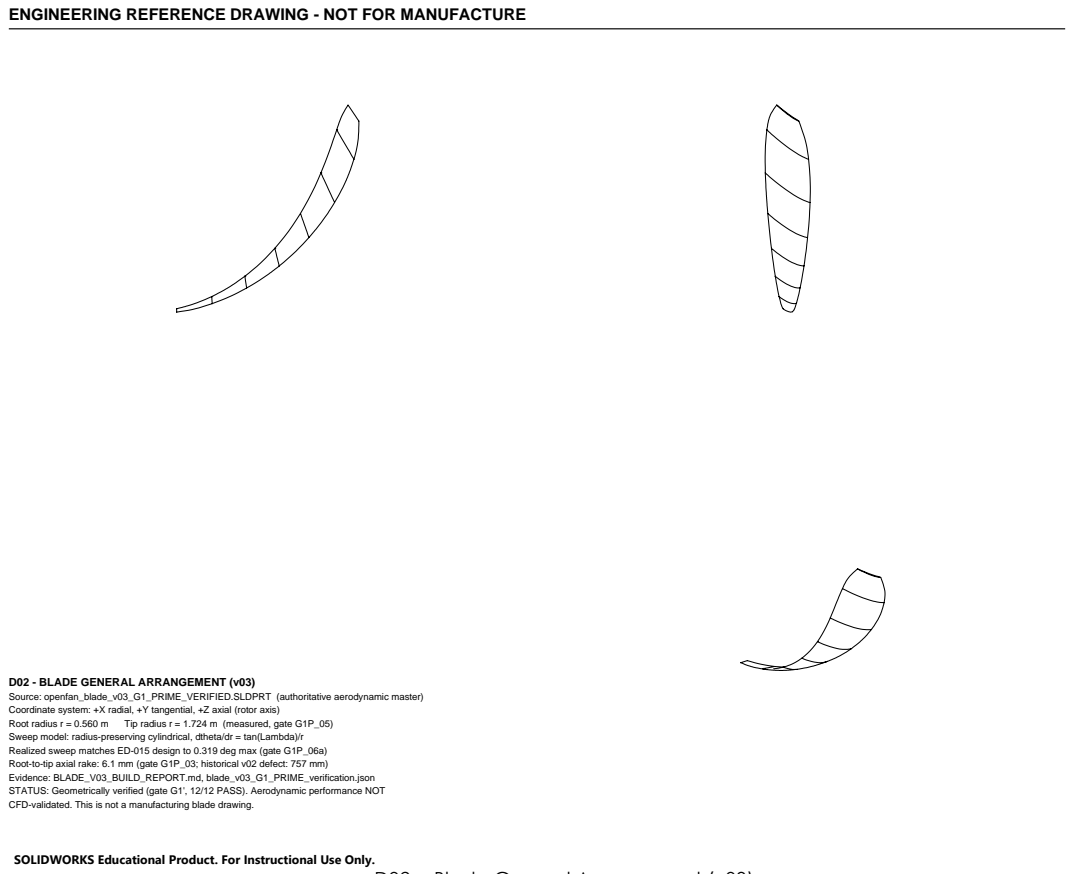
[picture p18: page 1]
Root radius r = 0.560 m; Tip radius r = 1.724 m (measured, gate G1P_05)

ENGINEERING REFERENCE DRAWING - NOT FOR MANUFACTURE

D02 - BLADE GENERAL ARRANGEMENT (v03)
Source: openfan_blade_v03_G1_PRIME_VERIFIED.SLDPRT (authoritative aerodynamic master)
Coordinate system: +X radial, +Y tangential, +Z axial (rotor axis)
Sweep model: radius-preserving cylindrical, dtheta/dr = tan(Lambda)/r
Realized sweep matches ED-015 design to 0.319 deg max (gate G1P_06a)
Root-to-tip axial rake: 6.1 mm (gate G1P_03; historical v02 defect: 757 mm)
Evidence: BLADE_V03_BUILD_REPORT.md, blade_v03_G1_PRIME_verification.json
STATUS: Geometrically verified (gate G1', 12/12 PASS). Aerodynamic performance NOT
CFD-validated. This is not a manufacturing blade drawing.

SOLIDWORKS Educational Product. For Instructional Use Only.

D02 -- Blade General Arrangement (v03)

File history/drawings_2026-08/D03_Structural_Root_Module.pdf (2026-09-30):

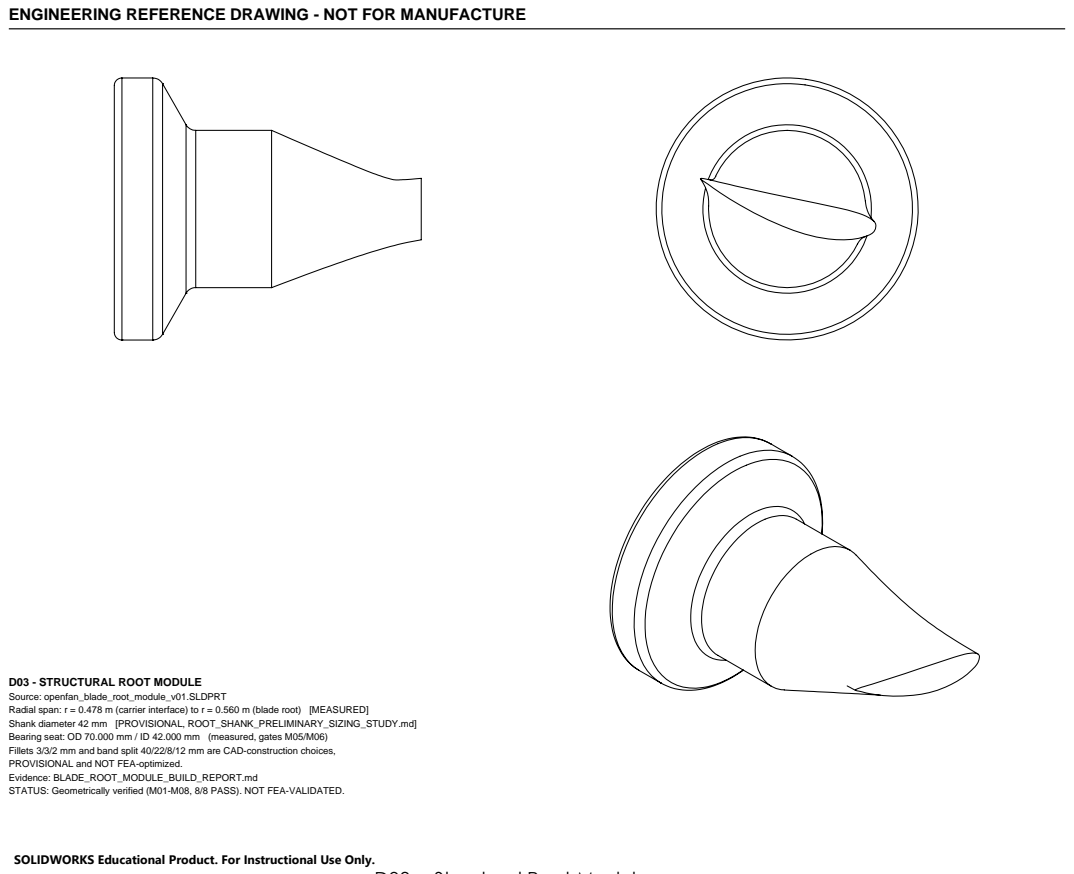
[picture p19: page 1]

ENGINEERING REFERENCE DRAWING - NOT FOR MANUFACTURE

D03 - STRUCTURAL ROOT MODULE
Source: openfan_blade_root_module_v01.SLDPRT
Radial span: r = 0.478 m (carrier interface) to r = 0.560 m (blade root) [MEASURED]
Shank diameter 42 mm [PROVISIONAL, ROOT_SHANK_PRELIMINARY_SIZING_STUDY.md]
Bearing seat: OD 70.000 mm / ID 42.000 mm (measured, gates M05/M06)
Fillets 3/3/2 mm and band split 40/22/8/12 mm are CAD-construction choices,
PROVISIONAL and NOT FEA-optimized.
Evidence: BLADE_ROOT_MODULE_BUILD_REPORT.md
STATUS: Geometrically verified (M01-M08, 8/8 PASS). NOT FEA-VALIDATED.

SOLIDWORKS Educational Product. For Instructional Use Only.

D03 -- Structural Root Module

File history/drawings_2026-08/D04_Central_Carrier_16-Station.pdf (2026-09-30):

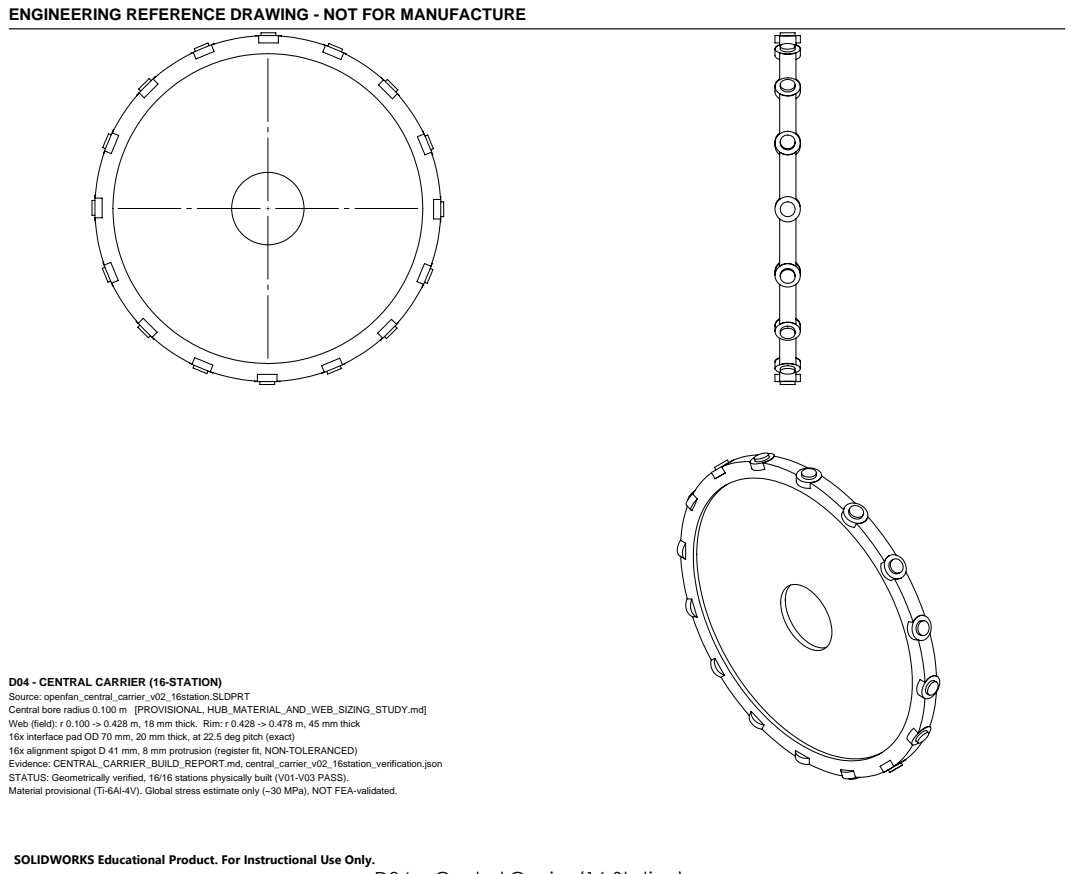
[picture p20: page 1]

ENGINEERING REFERENCE DRAWING - NOT FOR MANUFACTURE

D04 - CENTRAL CARRIER (16-STATION)
Source: openfan_central_carrier_v02_16station.SLDPRT
Central bore radius 0.100 m [PROVISIONAL, HUB_MATERIAL_AND_WEB_SIZING_STUDY.md]
Web (field): r 0.100 -> 0.428 m, 18 mm thick. Rim: r 0.428 -> 0.478 m, 45 mm thick
16x interface pad OD 70 mm, 20 mm thick, at 22.5 deg pitch (exact)
16x alignment spigot D 41 mm, 8 mm protrusion (register fit, NON-TOLERANCED)
Evidence: CENTRAL_CARRIER_BUILD_REPORT.md, central_carrier_v02_16station_verification.json
STATUS: Geometrically verified, 16/16 stations physically built (V01-V03 PASS).
Material provisional (Ti-6Al-4V). Global stress estimate only (~30 MPa), NOT FEA-validated.

SOLIDWORKS Educational Product. For Instructional Use Only.

D04 -- Central Carrier (16-Station)

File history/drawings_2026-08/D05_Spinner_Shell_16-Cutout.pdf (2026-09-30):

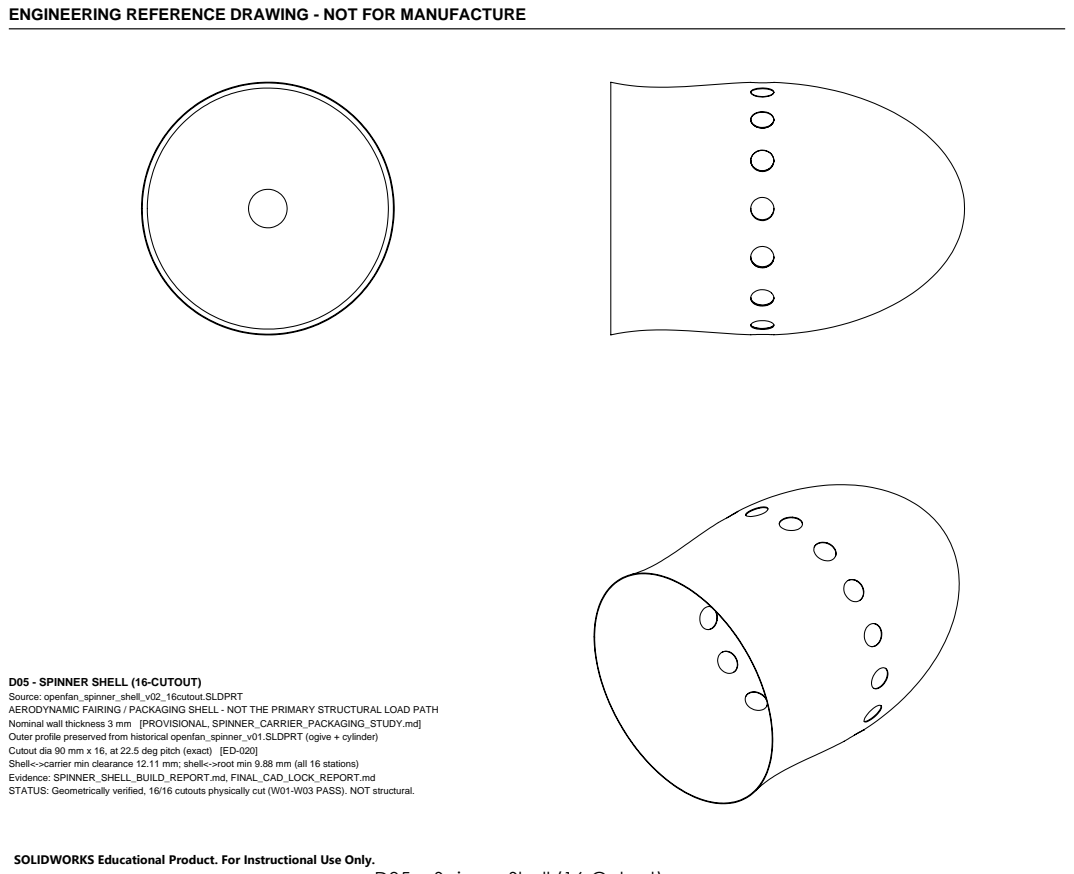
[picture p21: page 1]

ENGINEERING REFERENCE DRAWING - NOT FOR MANUFACTURE

D05 - SPINNER SHELL (16-CUTOUT)
Source: openfan_spinner_shell_v02_16cutout.SLDPRT
AERODYNAMIC FAIRING / PACKAGING SHELL - NOT THE PRIMARY STRUCTURAL LOAD PATH
Nominal wall thickness 3 mm [PROVISIONAL, SPINNER_CARRIER_PACKAGING_STUDY.md]
Outer profile preserved from historical openfan_spinner_v01.SLDPRT (ogive + cylinder)
Cutout dia 90 mm x 16, at 22.5 deg pitch (exact) [ED-020]
Shell<->carrier min clearance 12.11 mm; shell<->root min 9.88 mm (all 16 stations)
Evidence: SPINNER_SHELL_BUILD_REPORT.md, FINAL_CAD_LOCK_REPORT.md
STATUS: Geometrically verified, 16/16 cutouts physically cut (W01-W03 PASS). NOT structural.

SOLIDWORKS Educational Product. For Instructional Use Only.

D05 -- Spinner Shell (16-Cutout)
